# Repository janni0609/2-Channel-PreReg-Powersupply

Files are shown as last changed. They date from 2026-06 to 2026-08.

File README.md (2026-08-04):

# 2-Channel Pre-Regulated Bench Power Supply

A two-channel laboratory bench power supply, **0–36 V / 0–2 A per channel**, fully
isolated between channels. Each channel pairs a **tracking switch-mode
pre-regulator** with a **linear post-regulator**, so it has the low output noise of
a linear supply without the heat of dropping 36 V across a pass transistor.

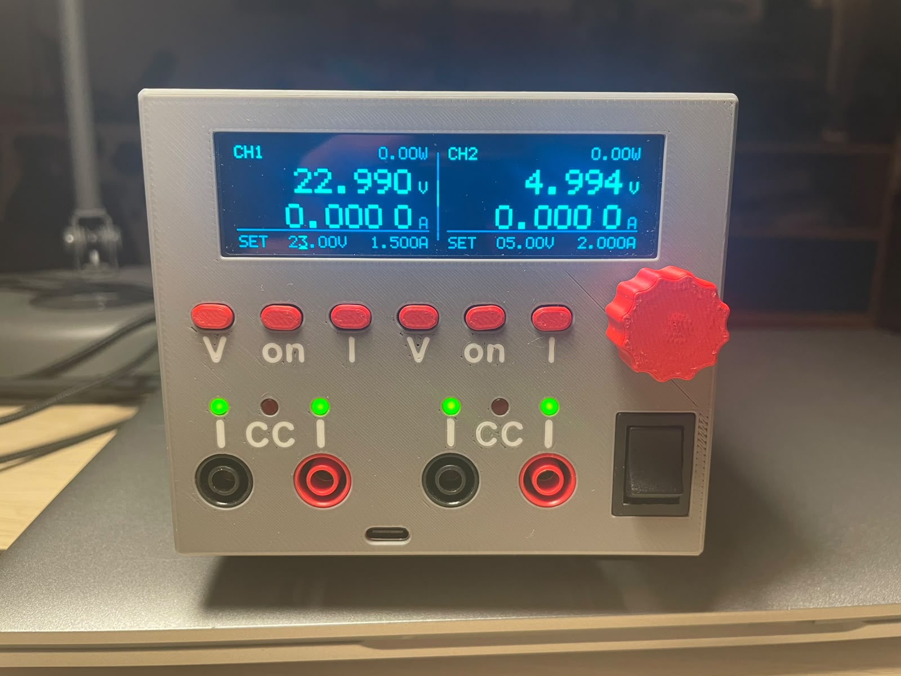
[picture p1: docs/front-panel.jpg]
Front panel of the assembled supply, both channels running


Everything here is open: KiCad 10 schematics and layout for both boards, the
firmware for all three microcontrollers, and the design calculations (loop
stability, DC/DC dimensioning, ADC/DAC error budget) that back the component
values.

**Status: built and working.** Both PCBs are assembled and running. One known
footprint error, see [Known issues](#known-issues).

**Schematics in your browser (KiCanvas):**
[Main board](https://kicanvas.org/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)
· [Front panel](https://kicanvas.org/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)

---

## Specifications

| Parameter | Value |
| --- | --- |
| Channels | 2, independent, galvanically isolated from each other and from the control logic |
| Output voltage | 0 … 36 V per channel |
| Output current | 0 … 2 A per channel (setpoint = current limit, CV/CC) |
| Setpoint resolution | 12-bit DAC ≈ 8.6 mV / 0.49 mA; front panel edits in 10 mV / 1 mA steps |
| Measurement resolution | 16-bit ADC, ~1.9 mV / ~0.1 mA; displayed as 3 decimals (V) and 4 decimals (A) |
| Accuracy | ±3–4 % uncalibrated (DAC band gap dominates). **Measured after calibration, worst of both channels: setpoint ±17 mV / ±1.3 mA, readback ±2.8 mV / ±3.7 mA** — see [Measured accuracy](#measured-accuracy) |
| Protection | Per-channel over-temperature (settable, default 60 °C), system OTP on the heatsink, comms-loss shutdown, input fuses + TVS |
| Regulation | Analog CV and CC loops per channel; MCU sets the references, does not close the loop. CC is indicated by a panel LED driven straight from the loop |
| Display | 256×64 SSD1322 OLED |
| Remote control | SCPI over Ethernet (raw TCP, port 5025) and USB CDC (front-panel USB-C) |
| Cooling | Temperature-controlled 4-wire PWM fan |
| Input | 2 × 40 V DC (channels) + 12 V DC (logic) — see [Power input](#power-input) |

---

## How it works

### Power path (one channel)

```text
40 V in ──▶ LT8612 tracking buck ──▶ Vpre = Vout + 2.2 V ──▶ TIP125 linear pass ──▶ OUT
                    ▲                                              ▲
                    └────────── follows the output ────────────────┘
```

The buck converter does not produce a fixed rail — it **tracks the output**,
holding just 2.2 V of headroom across the linear stage. At full load that is
~200 mV across the 0.1 Ω shunt plus ~2 V across the TIP125 Darlington, i.e. a few
watts of dissipation instead of the ~70 W a plain 40 V linear supply would burn at
0 V out into 2 A.

The linear stage is a classic op-amp regulator built around a **TIP125** PNP
Darlington driven by a **TLV4387** quad op-amp:

- **Voltage loop** — a 4-resistor difference amplifier across OUT+/OUT− scales the
  output by 1/15 (0.06935) and compares it against `Vset` from the DAC.
- **Current loop** — a 0.1 Ω shunt (PCS2512, 1 %, 0.4 W at 2 A) is amplified ×12.25
  and compared against `Iset`. Whichever loop demands less current wins, giving
  automatic CV → CC crossover. The crossover point itself is picked off as a
  `CC/CV` signal that lights the front-panel **CC** lamp directly — no firmware in
  the path, so the indicator is as fast as the loop it reports on.

Both loops are compensated deliberately, not guessed — see
[`Calc/Stability/`](Calc/Stability/) for the plant models, the chosen compensator
values, and the loop-gain / step-response plots.

Per-channel auxiliary rails come off the 40 V input: **LMR51606** buck → 4.5 V,
**AP7384-33Y** → 3.3 V for the MCU and converters, and an **LM2776** charge pump +
**XC6901** negative LDO → −1.2 V so the op-amps can swing cleanly down to 0 V.

### Control architecture

```text
        ┌──────────────── Front panel ────────────────┐
        │  SSD1322 OLED · encoder · 6 buttons · LEDs  │
        └──────────────────────┬──────────────────────┘
                               │ SPI / I²C
                    ┌──────────┴──────────┐        ┌──────────────┐
   Ethernet ────────┤   RP2350 "Brain"    ├────────┤ W5500 · USB  │ SCPI
                    └─────┬─────────┬─────┘        └──────────────┘
                UART0 ◄───┘         └───► UART1     (1 Mbps, ISO6721 isolated)
                  │                         │
        ┌─────────┴────────┐      ┌─────────┴────────┐
        │ ATtiny1614  CH1  │      │ ATtiny1614  CH2  │
        │ ADS1118 · MCP48F │      │ ADS1118 · MCP48F │
        └──────────────────┘      └──────────────────┘
```

Each channel has its own **ATtiny1614** living in that channel's isolated ground
domain. It drives the **MCP48FVB22** dual DAC (the V and I references for the
analog loops), reads the **ADS1118** 16-bit ADC (output voltage and shunt current),
monitors an NTC, sequences the two enable lines, and stores its calibration in
EEPROM. Over-temperature shutdown happens in the channel MCU itself, so a hung
UART link can never leave an output enabled.

The **RP2350** brain owns the user interface and all remote control. It never
touches the analog loops directly; it only sends setpoints and reads telemetry
over the two isolated 1 Mbps UART links.

---

## Boards

### `hardware_main/` — main board (`DualPreRegPowerSupply.kicad_pro`)

Both power channels, both channel MCUs, the brain, and the digital supply on one
PCB. Hierarchical sheets:

| Sheet | Contents |
| --- | --- |
| `Ch1Power` (×2 instances) | One complete channel — the sheet below is instantiated twice |
| ├ `Input` | 40 V input, fuse, TVS, common-mode choke |
| ├ `Power` | Channel aux rails: 4.5 V, 3.3 V, −1.2 V |
| ├ `DCDCTracking` | LT8612 tracking pre-regulator |
| ├ `Linear_PostReg` | TIP125 pass element, V and I loops, shunt, sense amps |
| ├ `DAC_ADC` | MCP48FVB22 DAC, ADS1118 ADC, filtering |
| └ `MCU` | ATtiny1614, NTC, ISO6721 isolated UART, UPDI header |
| `Control` | RP2350-Tiny, W5500 Ethernet, front-panel connectors, fan |
| └ `Digi_Power` | 12 V input → AP63200WU → 3.3 V logic rail |

Fabrication outputs (Gerbers, BOM, CPL) are in
[`hardware_main/production/`](hardware_main/production/); an interactive BOM is at
[`hardware_main/bom/ibom.html`](hardware_main/bom/ibom.html).

### `hardware_front/` — front panel (`Front Panel.kicad_pro`)

The user interface board: SSD1322 OLED header, rotary encoder with push button,
6 push buttons, 6 status LEDs (per channel: two green output-ON indicators, one
over each banana-jack pair, plus the red CC lamp), buzzer, and an **MCP23008** I²C
expander that collects the buttons and drives the buzzer. The green indicators run
off the corresponding channel's isolated 3.3 V rail, so each half of the panel
stays in its own ground domain. Fabrication outputs in
[`hardware_front/production/`](hardware_front/production/).

---

## Firmware

Both projects build with **PlatformIO**.

### `firmware/brain/main/` — RP2350 brain

Waveshare RP2350-Tiny (built against `waveshare_rp2350_zero`). Handles the OLED
UI, encoder and buttons, fan control, the UART links to both channels, and the
SCPI server on Ethernet + USB.

```sh
cd firmware/brain/main
pio run                 # build
pio run -t upload       # flash (UPF2 / USB bootloader)
```

RP2350 pin map (also documented at the top of `platformio.ini`):

| Function | Pins |
| --- | --- |
| OLED SSD1322 (SPI1) | RES 9, SCK 10, MOSI 11, DC 12, CS 13 |
| Rotary encoder (PIO quadrature) | A 14, B 15 |
| W5500 Ethernet (SPI0) | CS 17, SCK 18, MOSI 19, MISO 20, RST 21, INT 22 |
| MCP23008 expander (I²C1) | SDA 6, SCL 7, INT 8 |
| Channel UARTs @ 1 Mbps | CH1: TX 0 / RX 1 · CH2: TX 4 / RX 5 |
| Heatsink NTC / fan PWM | ADC3 (GPIO29) / GPIO26 (25 kHz) |

[`firmware/brain/UI-test/`](firmware/brain/UI-test/) is the earlier UI-only
prototype the production firmware grew out of; it is kept for display work without
the power hardware attached.

### `firmware/channel/` — ATtiny1614 channel

megaTinyCore, 16 MHz internal oscillator, flashed over UPDI. Layered cooperative
super-loop with an explicit state machine
(`INIT → SELFTEST → IDLE ↔ RUN → FAULT`). See
[`firmware/channel/README.md`](firmware/channel/README.md) for the module tree,
the state machine, and the calibration procedure.

```sh
cd firmware/channel
pio run -t fuses        # once: set OSCCFG to 16 MHz (required!)
pio run -t upload       # flash over UPDI
```

> The `-t fuses` step is not optional on a fresh part. The default fuse selects the
> 20 MHz oscillator base; with a 16 MHz build every timing (UART baud, delays,
> telemetry period) comes out 25 % off.

### Brain ↔ channel protocol

A small binary framing: `[SOF 0xA5][LEN][CMD][payload][CRC8]`, defined in
`firmware/channel/include/protocol.h` (mirrored into the brain project). The
channel pushes a telemetry frame every 100 ms (V, I, P, temperature, state,
flags) and ACK/NACKs every command. If the brain goes quiet for 1 s while an
output is on, the channel turns that output off by itself.

---

## Remote control (SCPI)

The instrument speaks an **SCPI-1999 / IEEE-488.2 subset** on two transports at
once — raw TCP port 5025 over Ethernet, and USB CDC — so it works with PyVISA,
NI-MAX, `lxi`, or a plain terminal.

```text
*IDN?                 → PreReg,PSU-2CH-36V2A,SN00001,0.2.0
APPL CH1,12.0,1.0
OUTP ON,(@1)
MEAS:VOLT? (@1)       → 12.001
MEAS:CURR? (@1)       → 0.2531
```

Channel lists (`(@1)`, `(@1,2)`) and stateful `INST:NSEL` selection are both
supported, along with the STATus register model, an error queue, and the
CALibration subsystem. The full command reference — including UART mappings and
known deviations — is in [`firmware/SCPI/commands.md`](firmware/SCPI/commands.md).

Network settings (DHCP or static IP, netmask, gateway, hostname) are configured
from the front panel under *Settings → Network*, and only take effect on **Apply**,
so a half-typed IP never goes live.

---

## Front panel

The main screen shows both channels side by side: measured voltage and current in
large digits, output power in the corner, and the active setpoints on the bottom
row. Six buttons (`V · on · I` per channel) select what the encoder edits and
toggle each output; the encoder push button moves the digit cursor — underlined on
screen — so any digit can be dialled directly instead of scrolling through the
whole range.

Below the buttons, each channel has two green output-ON LEDs flanking a red **CC**
lamp that lights whenever that channel leaves constant-voltage regulation, then the
output banana jacks. The USB-C port for SCPI-over-USB and firmware updates sits in
the middle of the panel; the mains switch is on the right. The enclosure is 3D
printed.

The Settings menu (encoder-driven, see
[`firmware/brain/UI-test/Settings.md`](firmware/brain/UI-test/Settings.md))
covers per-channel diagnostics (temperature, DAC/ADC/comms health, operating
hours, stored calibration values, the manual 2-point calibration wizard), the
temperature and fan curve (start temp, max temp, minimum speed, system OTP),
the network configuration, and system items (firmware version, beeper, brain
runtime, remember-setpoints-on-restart).

---

## Calibration

Every signal path — `VSET`, `ISET`, `VMEAS`, `IMEAS`, per channel — is a straight
line `y = gain·x + offset` fitted from two points and stored in the channel's
EEPROM. This is **required**, not optional: the MCP48FVB22 uses its internal
1.22 V band gap (Vref is not routed on the PCB), and that band gap is specified to
±3.3 %. Calibration removes it, along with the 1 % resistor and shunt tolerances,
leaving roughly ±0.05 % on voltage and ±0.1–0.2 % on current. Until a channel has
been calibrated it reports `FLAG_CAL_INVALID`.

Run it from the front panel (*Settings → Channel n → Manual Cal V/I*, with a
DMM on the output) or remotely via `CAL:POIN` / `CAL:COMM`. Full error budget and
where each term comes from:
[`Calc/DAC_ADC/DAC_ADC_Accuracy_Analysis.md`](Calc/DAC_ADC/DAC_ADC_Accuracy_Analysis.md).

---

## Measured accuracy

Both channels were measured against a **Siglent SDM3065X** 6½-digit DMM on
2026-08-03/04, using [`Calc/evaluation/psu_accuracy.py`](Calc/evaluation/) — a
ramp of the full range in fine steps, comparing three numbers at every step:

| | source | exercises |
| --- | --- | --- |
| setpoint | what was written with `VOLT` / `CURR` | DAC → `VSET`/`ISET` chain |
| readback | `MEAS:VOLT?` / `MEAS:CURR?` | sense amp → ADC → `VMEAS`/`IMEAS` chain |
| truth | SDM3065X | — |

Voltage: 0 → 36 V in 500 mV steps, open circuit. Current: 0 → 2 A in 25 mA steps
into the DMM's own current input as the load, 2 V compliance. Figures are for the
instrument **as it stands today**, i.e. calibrated, and exclude the two endpoints
the channel physically cannot reach: the 0 V / 0 A setpoint (output floor, not an
accuracy error) and the clipped top of the current range (see
[Known issues](#known-issues)). `psu_accuracy.py` applies both exclusions itself,
so these numbers come straight out of its report; `--keep-endpoints` reports every
point instead.

### Results

| | CH1 setpoint | CH1 readback | CH2 setpoint | CH2 readback |
| --- | --- | --- | --- | --- |
| **Voltage** rms | 8.8 mV | **0.74 mV** | 5.1 mV | 1.4 mV |
| worst | 16.5 mV | 2.1 mV | 11.6 mV | 2.8 mV |
| gain error | −0.0005 % | +0.0025 % | −0.0024 % | −0.0003 % |
| **Current** rms | **0.30 mA** | 0.12 mA | **0.52 mA** | 0.16 mA |
| worst | 0.79 mA | 0.39 mA | 1.36 mA | 0.51 mA |
| gain error | +0.012 % | +0.013 % | +0.035 % | +0.019 % |

Both current columns were re-measured on 2026-08-04, after the measure-path
calibration bug was found and fixed and both channels' `IMEAS` re-calibrated.
The readback paths went from 0.78 mA rms / +0.135 % gain / −1.38 mA offset (CH1)
and 2.0 mA rms / +0.176 % gain (CH2) to the numbers above — an order of
magnitude, and the −1.4 mA offset that had been blamed on the shunt turned out to
be an artefact of the bad fit.

In short, worst of both channels: **voltage setpoint ±17 mV (≈0.05 % FS), voltage
readback ±2.8 mV, current setpoint ±1.4 mA (≈0.07 % FS), current readback
±0.51 mA**. Every voltage gain error is inside ±0.003 % and every current gain
error is now inside ±0.04 %, so the calibration is doing its job on every path.
The current readback is at ~5 ADC LSB worst case.

<picture>
  <source media="(prefers-color-scheme: dark)" srcset="Calc/evaluation/results/ramp_v_ch1_20260804_231349_ch1_v_baseline_dark.png">
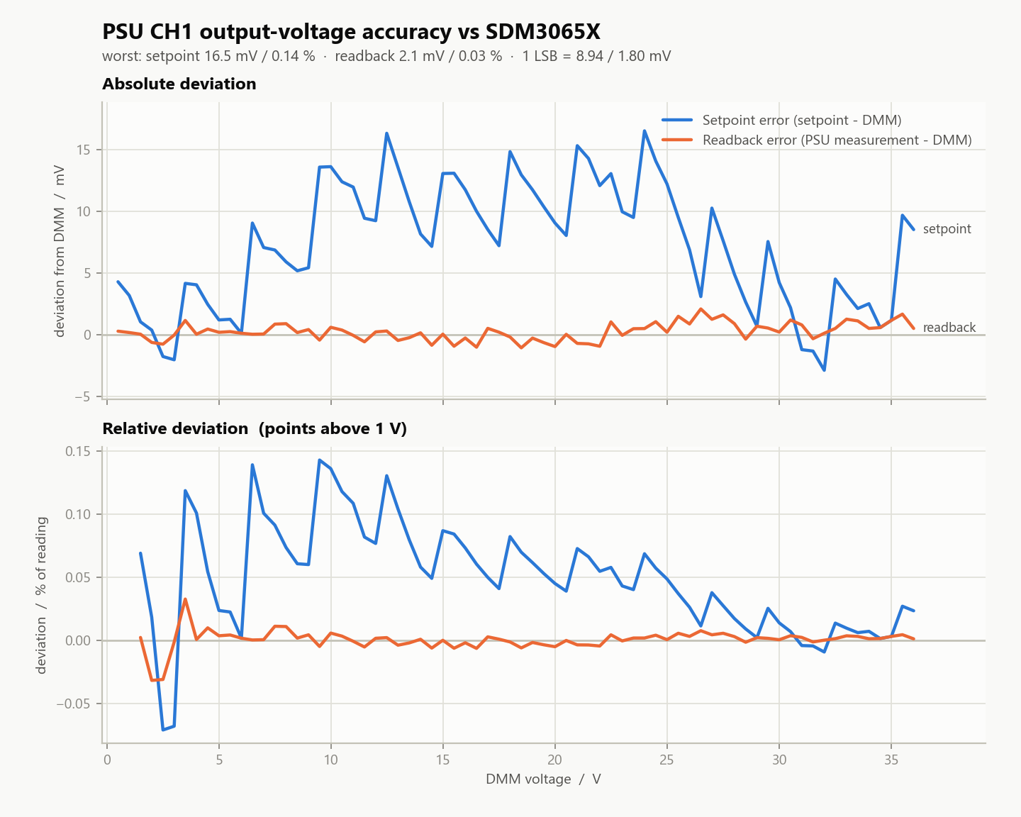
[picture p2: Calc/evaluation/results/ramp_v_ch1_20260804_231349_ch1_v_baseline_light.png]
CH1 output-voltage accuracy against the SDM3065X: absolute and relative deviation
  
</picture>

The voltage setpoint trace is the interesting one. Its error is **not**
calibration error — it is the 12-bit DAC. The sawtooth is the ±½ LSB rounding of
a requested millivolt onto the ~8.9 mV code grid, and the slow envelope on top is
the DAC's own INL (specified ±2 LSB). A 2-point calibration pins the two
endpoints and cannot bend to follow a bow between them, which is why
re-calibrating an already-calibrated channel here changes nothing. The readback
trace sits flat at the ADC's ~1.8 mV quantum. **This is the hardware floor, not a
tuning problem** — improving it needs an external DAC reference (the `Vref` pin is
not routed) or more DAC bits.

<picture>
  <source media="(prefers-color-scheme: dark)" srcset="Calc/evaluation/results/ramp_i_ch1_20260804_224335_ch1_imeas_fix_dark.png">
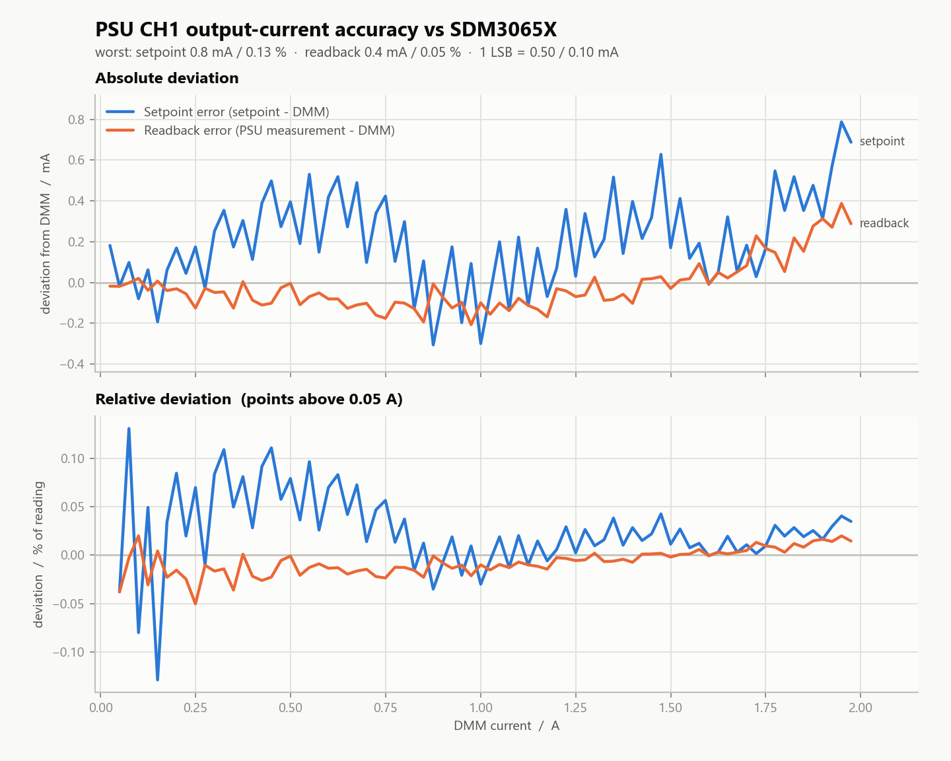
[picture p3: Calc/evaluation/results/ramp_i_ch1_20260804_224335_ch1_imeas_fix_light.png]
CH1 output-current accuracy against the SDM3065X after calibration
  
</picture>

Current is the opposite case, and shows what calibration *can* do. Both of CH1's
current paths were a clean tilt beforehand — an error proportional to reading,
which is exactly the shape a 2-point fit removes. The setpoint went from +0.176 %
gain (−1.2 mA at 100 mA rising to +1.8 mA at 2 A) to +0.012 %, rms 0.89 →
0.30 mA; the readback went from +0.135 % gain with a −1.38 mA offset to
+0.013 %, rms 0.78 → 0.12 mA. Both traces are now flat inside ±0.8 mA across the
range, with the readback at ~4 ADC LSB. CH2 behaves the same way.

**Rule of thumb from this:** plot the error against reading before calibrating. A
*tilt*, or a constant offset, is gain/offset error and a 2-point fit removes it
exactly. A *bow* between the cal points is INL and it will not — which is why the
voltage setpoint above does not improve however often it is re-run. The report's
`worst non-linearity` row measures that bow; compare it against the quantisation
floor printed beneath it.

All raw data, per-run reports and both channels' plots are in
[`Calc/evaluation/results/`](Calc/evaluation/results/); the harness, wiring and
options are documented in [`Calc/evaluation/README.md`](Calc/evaluation/README.md).

---

## Power input

The supply is fed from three off-the-shelf Mean Well modules:

| Input | Supply | Feeds |
| --- | --- | --- |
| J101 | Mean Well **LRS-75-36**, trimmed to **40 V** | Channel 1 |
| J601 | Mean Well **LRS-75-36**, trimmed to **40 V** | Channel 2 |
| J901 | Mean Well **RS-15-12** (12 V) | Brain, OLED, Ethernet, fan |

Each channel input has its own 3.5 A fuse, TVS clamp, and common-mode choke.
Because the two channel supplies are separate isolated modules and the UART links
are isolated with ISO6721 digital isolators, the two outputs are genuinely
floating and independent — they can be wired in series or referenced separately.

Outputs terminate in front-panel banana jacks (J201/J202 and J402/J403).

---

## Repository layout

```text
hardware_main/     KiCad 10 project — main board (power, MCUs, brain)
hardware_front/    KiCad 10 project — front panel (OLED, encoder, buttons)
firmware/
  brain/main/      RP2350 production firmware (UI + comms + SCPI)
  brain/UI-test/   Earlier UI-only prototype
  channel/         ATtiny1614 channel firmware
  SCPI/            SCPI command reference
  requirements/    Original firmware requirements notes
  Datasheets/      Datasheets for the main ICs
Calc/
  Stability/       V and I loop compensation — notebooks + typeset report
  DCDC Calc/       LMR51606 40 V → 4.5 V aux buck design
  DAC_ADC/         Setpoint/measurement error budget
  evaluation/      Bench accuracy measurement vs a reference DMM (+ raw results)
```

---

## Design notes and calculations

- [`Calc/Stability/stepbystep/`](Calc/Stability/stepbystep/) — Jupyter notebooks
  deriving the voltage and current loop transfer functions (including the TIP125's
  β(s) roll-off and the op-amp GBW corner), the chosen compensator values, load
  sweeps, and step responses. The typeset summary is
  `Calc/Stability/stepbystep/report/loop_analysis.pdf`.
- [`Calc/DCDC Calc/LMR51606X_40V_4V5_200mA_design.md`](Calc/DCDC%20Calc/LMR51606X_40V_4V5_200mA_design.md)
  — full worked design of the 40 V → 4.5 V auxiliary buck.
- [`Calc/DAC_ADC/DAC_ADC_Accuracy_Analysis.md`](Calc/DAC_ADC/DAC_ADC_Accuracy_Analysis.md)
  — where every microvolt of error comes from, and what calibration does and does
  not fix.

---

## Known issues

- **AP7384-33Y footprint (channel 3.3 V LDO)** — the footprint on the main board is
  wrong; the part needs rework/adaptation to fit. Fix before ordering new boards.
- The ADS1118 PGA is **pinned to ±4.096 V** rather than autoscaling. Each PGA range
  has its own gain/offset error and input impedance, so a single 2-point cal line
  cannot describe all of them — autoscaling made readings drift away from the
  calibration points. Re-enabling it requires per-range calibration
  (`ADC_PGA_*_INDEX` in `firmware/channel/include/config.h`).
- **Neither channel reaches its rated 2.000 A.** The ISET DAC clips at ~1.99 A on
  CH1 and ~1.95 A on CH2 (both setpoints above the ceiling return the identical
  current, and the readback agrees). Full scale is 2.44 V ÷ 1.225 V/A = 1.99 A,
  but `DEFAULT_I_DIV` in `calibration.cpp` assumes 1.2 → 2.033 A and
  `SETPOINT_I_MAX_MA` is 2000; the channel spread on top is band-gap and shunt
  tolerance. The top ~1–2 % of the current range is not reachable.
- `CALibration:DATA?` returns NaN over SCPI: gain/offset cannot currently be read
  back across the channel link. `CAL:POINt`/`CAL:COMMit` are also fire-and-forget
  — the channel's NACK lands in `lastNackCmd` and the SCPI handler never looks at
  it — so a rejected commit is invisible to the host. Between them these kept a
  (now fixed) measure-path calibration bug hidden for far longer than it should
  have been. Until they are addressed, re-drive the cal points and check the
  readback residual (as `psu_accuracy.py` now does) rather than trusting
  `CAL:VALid?`.
- **A setpoint written immediately after `CAL:COMMit` is occasionally dropped.**
  Seen 3/3 times as the first `CURR` after committing `IMEAS` in a full
  calibration sequence, and 0/17 in isolated retries — so it is real but not yet
  root-caused. Ruled out: the channel is not stalled by the EEPROM write (the
  link never drops, `OUTP?` held over 3592 samples across a commit), and it is
  not a frame-size overflow. Leave a settle after a commit, and verify setpoints
  actually landed before measuring against them.
- The hostname set in *Settings → Network* is stored and displayed, but the stock
  Ethernet DHCP client does not advertise it to the DHCP server.
- The CV/CC mode is shown on the panel by a hardware-driven LED, but the `CC/CV`
  signal is not routed to a channel MCU pin, so the regulation mode cannot be
  queried over SCPI (`STAT:OPER` has no constant-current bit).

---

## Tools

KiCad 10 · PlatformIO (`raspberrypi` + `atmelmegaavr` platforms) · megaTinyCore ·
Arduino-Pico core · Python/Jupyter for the analysis notebooks.

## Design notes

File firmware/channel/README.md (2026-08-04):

# Channel firmware (ATtiny1614)

Firmware for one power-supply **channel** MCU. Each channel drives its own
ADC + DAC and talks to the **Brain** (RP2350) over UART. Built with
**megaTinyCore** (Arduino) under PlatformIO.

## Build / flash

```sh
pio run                 # build
pio run -t upload       # flash via UPDI (SerialUPDI by default)
pio device monitor      # 1000000 baud (1 Mbps), the Brain link
```

Adjust `upload_protocol` in `platformio.ini` for your UPDI programmer.

**Flashing does not wipe the calibration.** `-t upload` chip-erases, but both
chips have `SYSCFG0 = 0xC5`, i.e. the EESAVE fuse is set, so EEPROM survives
(verified by reading it back byte-for-byte either side of an upload). If that
fuse is ever cleared, back the EEPROM up first and restore it afterwards:

```sh
avrdude -c serialupdi -p attiny1614 -P COM<n> -b 115200 -U eeprom:r:backup.bin:r
```

That same read is currently the only way to recover the stored gain/offset
values, since `CAL:DATA?` returns NaN over SCPI.

## Architecture

Layered, cooperative super-loop (no RTOS). One shared `g_state` is the single
source of truth; modules update it, `comms` serializes it into telemetry.

```
main.cpp            super-loop scheduler + g_state
fsm.cpp             INIT -> SELFTEST -> IDLE <-> RUN -> FAULT
include/
  config.h          pin map, limits, tunables
  protocol.h        shared binary UART protocol (COPY into the Brain project)
src/hal/
  spi_bus.*         shared SPI, per-device mode switch + CS framing
  board.*           enable lines + NTC analog input
  storage.*         calibration EEPROM (magic + version + CRC16)
src/drivers/
  ads1118.*         16-bit ADC: single-shot, config readback self-test
  mcp48fvb22.*      dual 12-bit DAC: band-gap ref, gain 1x
src/app/
  measure.*         non-blocking V/I acquisition, PGA autoscale, power
  setpoint.*        engineering setpoint -> DAC code (via calibration)
  calibration.*     2-point linear cal for the 4 paths
  thermal.*         NTC -> degC, over-temp protection (independent of comms)
  output.*          enable sequencing (DCDC first, then linear)
  selftest.*        power-on ADC/DAC/temperature checks
  comms.*           frame parser, dispatch, telemetry/ACK/EVENT
```

### State machine

`SELFTEST` runs on boot; on pass -> `IDLE` (output off). `SET_OUTPUT 1` from
`IDLE` -> `RUN`. Over-temperature (>= 60 °C) from any state -> `FAULT`, which
forces both enable lines low. `FAULT` clears only via `RESET_FAULT` once the
temperature has dropped below 55 °C (hysteresis), then re-runs `SELFTEST`.

Over-temp protection runs in the thermal task + FSM, so a hung UART can never
keep the output enabled.

## UART protocol

Frame: `[SOF 0xA5][LEN][CMD][payload...][CRC8]`, little-endian, CRC-8 poly
0x07. See `include/protocol.h` for command IDs and payloads. The Channel pushes
`TELEMETRY` every 100 ms and ACK/NACKs every command; the Brain can also poll
with `GET_STATUS`.

Telemetry payload (16 B): `v_mV(i32) i_dmA(i32) p_mW(i32) temp_cC(i16)
state(u8) flags(u8)`.

## Calibration

Every signal path is `y = gain*x + offset`, calibrated from two points and
stored in EEPROM. Procedure, per target (`CAL_VSET/ISET/VMEAS/IMEAS`):

1. Drive a low point (set a setpoint, or just read at low signal), measure the
   true value externally, send `CAL_POINT{target, index=0, actual}`.
2. Repeat for a high point with `index=1`.
3. `CAL_COMMIT{target}` solves and persists the line.

`CAL_RESET{target}` restores compile-time defaults.

## Pin map (corrected from requirements)

| Signal | Pin  | Notes |
|---|---|---|
| SPI MOSI | PA1  | shared bus (ADC + DAC) |
| SPI MISO | PA2  | shared bus |
| SPI SCK | PA3  | shared bus |
| ADC_CS | PA4  | **was PA3 in requirements (collided with SCK)**  |
| DAC_CS | PA7  | |
| DAC_LAT | PA6  | held low (transparent latch) |
| Enable_DCDC  | PB1  | pre-regulator |
| Enable_lin | PA5  | linear post-regulator |
| NTC | PB0  | 10k NTC, Rtop=10k to VDD |
| UART TX/RX | PB2/PB3 | USART0 -> the `Serial` object |

## Assumptions to confirm

These were chosen to make the firmware complete and buildable; please verify
against the hardware:

1. **ADC_CS = PA4** (requirements listed PA3, which is SCK).
2. **Enable sequence**: pre-regulator (DCDC) is enabled before the linear
   stage, and disabled after it. Swap in `output.cpp` if the hardware wants the
   opposite order.
3. **Setpoint units**: `SET_VOLTAGE`/`SET_CURRENT` carry mV/mA. The default
   (uncalibrated) map treats them as desired DAC output mV (0..2440). The real
   mapping to the supply's output range is established by 2-point calibration;
   `FLAG_CAL_INVALID` is reported until then.
4. **DAC reference**: internal band gap, gain 1x -> 0..2.44 V full scale (the
   "0..2.5 V" spec). The band gap is ±3.3 %, so calibration is required.
5. **ADS1118 PGA** starts at ±4.096 V and autoscales up for small signals; the
   front end is assumed to keep inputs within ±4.096 V at full output.

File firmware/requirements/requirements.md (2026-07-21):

the firmware is for a lab bench powersupply projekt. 
the architecture of the powersupply is as follows

RP2350 (Waveshare RP2350-Tiny) is the main "brain".

the Powersuppy has two channes. each channes has its own MCU (Attiny 1614) that communicates with the ADC and DAC + periphials.

each attiny (i will call it channel) is connected to the RP2350 (i will call it brain) via UART.

**requirements for the Brain:**

it has to communicate with the channes.
    the brain should be able to send the channel a set volatage, set current, output state(on/off)

the Display has to be used (see ????? for a referance)

the brain is connected to an MCP23008 I/O expander via i2c (I2C1, 400 kHz fast mode).
    the MCP23008 has a rotary encoder connected and 6 buttons + 1 button on the encoder
    it also has a buzzer connected

**requirements for the channes:**

Attiny1614 at 3,3V
programmed at with platformIO.

the channel has to communicate with the brain. UART: (Tx -- PB2; Rx -- PB3)
Data to send to the Brain:
Output Volatge
Output Current
Output Power
Temperatur
Output State  (on/off)
Error messages

Data to recieved from Brain:
Set Volt
Set Current
Output State (on/off)
Data for calibration

the channel has to read the ADC (ADS1118IDGS) (SPI: MOSI -- PA1; MISO -- PA2; SCK -- PA3; ADC_CS -- PA4;)
Vmeas = AIN1 and AIN0
Imeas = AIN2 and AIN3
Do autoscaling of the input PGA

set the DAC (MCP48FVB22) (SPI: MOSI -- PA1; MISO -- PA2; SCK -- PA3; DAC_CS -- PA7; DAC_LAT -- PA6)
Vset = VOUT0
Iset = VOUT1
use internal reference
output 0 to 2,5V

The ADC and DAC has to be calibrated by a 2 point calibration.
for the calibration: a voltage/current will be set on the cannel and the actual measured volatge / current will be send by the brain. channel has to calculate cal values and store them in the eeprom

It has to be able to turn the output on and off with (Enable_DCDC -- PB1; Enable_lin -- PA5)

It has to read a NTC 10KOHM 3380K (PB0), NTC is set up with a R devider Rtop = 10k; Rbot = NTC

a self test has to be performed on startup:
test propper communication with chips and check if temp is in range (-10 to 60°C)

Output has to be turned off if temp reaches >60°C

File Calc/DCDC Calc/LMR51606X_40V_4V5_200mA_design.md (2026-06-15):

# LMR51606X Buck Converter Design — 40 V → 4.5 V @ 200 mA

Synchronous step-down (buck) converter design based on the **Texas Instruments LMR51606**
(datasheet *SLUSEY1B*, Rev. December 2023, located in this folder as `lmr51606.pdf`).

---

## 1. Design inputs & top-level decisions

| Parameter | Value | Source |
|---|---|---|
| Input voltage, V<sub>IN</sub> | **40 V** (treated as worst-case / max for ripple) | spec |
| Output voltage, V<sub>OUT</sub> | **4.5 V** | spec |
| Output current, I<sub>OUT</sub> | **200 mA** | spec |
| Switching frequency, f<sub>SW</sub> | **400 kHz** | fixed by "X" suffix |
| Reference voltage, V<sub>REF</sub> | **0.8 V** (±1.5 %) | datasheet §6.5 |
| Inductor ripple ratio, K<sub>IND</sub> | **≈ 0.5** | design choice (smaller L / more ripple) |
| EN / input UVLO | **EN tied directly to V<sub>IN</sub>** | design choice |
| Light-load mode | **PFM / auto-mode** | design choice |
| **Orderable part** | **LMR51606XDBVR** | 0.6 A, 400 kHz, PFM, adjustable, SOT-23-6 |

**Device suitability check:**
- V<sub>IN</sub> = 40 V is inside the 4 V–65 V operating range (abs. max 70 V). ✔
- 0.6 A device rating vs. 0.2 A load → **3× current headroom**. ✔
- V<sub>OUT</sub> = 4.5 V is inside the 0.8 V–28 V adjustable range. ✔

> **Note on input range:** the design is worst-cased at V<sub>IN</sub> = 40 V (the point of highest
> ripple current). It stays valid for any lower or varying input down to ≈ 4.9 V (see §2). If 40 V is
> actually the *minimum* of a higher range, the inductor and ripple numbers must be recomputed at the
> true maximum input.

---

## 2. Operating point & frequency-foldback check

Ideal buck duty cycle:

```
D = VOUT / VIN = 4.5 / 40 = 0.1125  (11.25 %)

tON  = D / fSW        = 0.1125 / 400 kHz   = 281 ns
tOFF = (1 - D) / fSW  = 0.8875 / 400 kHz   = 2219 ns
```

Compare against the device limits (datasheet §6.5 / §7.3.4):

| Limit | Value | Our value | OK? |
|---|---|---|---|
| Min ON time, t<sub>ON_MIN</sub> | 80 ns | 281 ns | ✔ (3.5×) |
| Max ON time, t<sub>ON(max)</sub> | 5 µs | 281 ns | ✔ |
| Min OFF time, t<sub>OFF_MIN</sub> | 200 ns | 2219 ns | ✔ (11×) |

Maximum / minimum input voltage **without** frequency foldback (Eq. 4 / Eq. 5):

```
VIN_MAX = VOUT / (fSW × tON_MIN)   = 4.5 / (400 kHz × 80 ns) = 140.6 V
VIN_MIN = VOUT / (1 - fSW × tOFF_MIN) = 4.5 / (1 - 0.08)     = 4.89 V
```

→ At V<sub>IN</sub> = 40 V the converter runs at a **clean fixed 400 kHz with no frequency foldback**.

---

## 3. Output-voltage feedback divider (R<sub>FBT</sub> / R<sub>FBB</sub>)

Datasheet Eq. 1 / Eq. 7:  `RFBT = (VOUT − VREF)/VREF × RFBB`

Required ratio: `RFBT/RFBB = (4.5 − 0.8)/0.8 = 4.625`

Chosen standard E96 (1 %) pair:

| Resistor | Value | Notes |
|---|---|---|
| **R<sub>FBT</sub>** (V<sub>OUT</sub> → FB) | **75.0 kΩ, 1 %** | within recommended 10 k–100 kΩ range |
| **R<sub>FBB</sub>** (FB → GND) | **16.2 kΩ, 1 %** | sets divider current |

Resulting output voltage:

```
VOUT = VREF × (1 + RFBT/RFBB) = 0.8 × (1 + 75.0k/16.2k) = 4.504 V   (+0.08 % vs target)
Idivider = VREF / RFBB = 0.8 / 16.2k = 49 µA
```

> Nominal set-point error is +0.08 %. The dominant error is component tolerance: ±1.5 % (V<sub>REF</sub>)
> plus ≈ ±1.4 % (two 1 % resistors, RSS) → use 1 % (or 0.5 %) resistors with a low temperature
> coefficient as recommended by TI. Place both resistors next to the FB pin (§9).

---

## 4. Inductor (L)

Minimum inductance, datasheet Eq. 9, with K<sub>IND</sub> = 0.5:

```
LMIN = (VIN_MAX − VOUT)/(IOUT × KIND) × VOUT/(VIN_MAX × fSW)
     = (40 − 4.5)/(0.2 × 0.5) × 4.5/(40 × 400 kHz)
     = 99.8 µH
```

→ **Choose a standard 100 µH inductor.**

Resulting ripple and currents (Eq. 8) with L = 100 µH:

```
ΔiL   = VOUT × (VIN_MAX − VOUT) / (VIN_MAX × L × fSW) = 99.8 mA   (KIND_actual = 0.50)
IL,peak   = IOUT + ΔiL/2 = 200 + 50 = 250 mA
IL,valley = IOUT − ΔiL/2 = 200 − 50 = 150 mA   (> 0 → continuous conduction at full load)
IL,rms    ≈ √(IOUT² + ΔiL²/12) = 202 mA
```

**Inductor selection requirements:**

| Parameter | Requirement | Reasoning |
|---|---|---|
| Inductance | **100 µH** (±20 %) | from Eq. 9, K<sub>IND</sub> = 0.5 |
| Saturation current, I<sub>sat</sub> | **≥ 1.5 A** | above the device max HS peak current limit (1.4 A) so the core does not saturate during an overload/short before cycle-by-cycle limiting acts |
| RMS current rating | **≥ 0.3 A** | operating I<sub>rms</sub> ≈ 0.2 A + margin |
| DCR | **≤ ~0.3 Ω** (lower = better) | efficiency; 0.3 Ω → ~12 mW loss |
| Type | Shielded ferrite | low EMI |

> If board size is critical, an inductor with I<sub>sat</sub> ≥ ~1.0 A still operates safely (operating peak
> is only 250 mA, and the IC's cycle-by-cycle current limit + hiccup protect the device); the ≥ 1.5 A
> recommendation is purely for full ruggedness against a hard short.

Candidate series (verify exact P/N, size and ratings against the requirements above): Coilcraft MSS-series /
XAL-series, Würth WE-LQS / WE-PD, Bourns SRR/SRN.

---

## 5. Output capacitor (C<sub>OUT</sub>)

**Selected: 22 µF / 25 V / X7R ceramic (ESR ≈ 5 mΩ).**

### 5.1 Steady-state ripple (Eq. 10 / Eq. 11)

```
ΔVOUT_C   = ΔiL / (8 × fSW × COUT) = 99.8 mA / (8 × 400 kHz × 22 µF) = 1.42 mV
ΔVOUT_ESR = ΔiL × ESR             = 99.8 mA × 5 mΩ                  = 0.50 mV
ΔVOUT(total) ≲ 2 mV   (the two terms are not in phase, so the real value is below their sum)
```

≈ 2 mV is **< 0.05 %** of 4.5 V — ripple is dominated by, and easily met by, a ceramic cap.

### 5.2 Load-transient limit (Eq. 12), full 0 → 200 mA step

```
COUT > ½ × 6 × (IOH − IOL) / (fSW × ΔVOUT_shoot)
  ΔVOUT_shoot = ±5 % (225 mV)  → COUT > 6.7 µF
  ΔVOUT_shoot = ±3 % (135 mV)  → COUT > 11.1 µF
```

A single **22 µF** part covers a full-load step to within ±3 % with margin, even after ceramic DC-bias
derating (a 25 V X7R at 4.5 V bias retains roughly 18–20 µF effective).

> A 10 µF / 25 V X7R is acceptable if minimizing size and only ±5 % transient is required.
> No load-transient spec was provided — values above assume a full 0 → 200 mA step; tighten C<sub>OUT</sub>
> if your overshoot/undershoot budget is smaller.

---

## 6. Input capacitor (C<sub>IN</sub>)

Datasheet §8.2.2.6: ≥ 2.2 µF ceramic, X7R/X5R, voltage rating **≥ 2 × V<sub>IN,max</sub>** = **≥ 80 V**.

| Component | Value | Rating | Notes |
|---|---|---|---|
| C<sub>IN</sub> (bulk decoupling) | **4.7 µF** (2.2 µF min) | **100 V**, X7R | 100 V rating gives ≥ 2× margin and offsets DC-bias derating of a 2.2 µF part |
| C<sub>IN_HF</sub> (high-freq bypass) | **0.1 µF** | 100 V, X7R | placed **directly** at the VIN/GND pins |

Input-cap RMS current:

```
ICIN,rms ≈ IOUT × √(D × (1 − D)) = 0.2 × √(0.1125 × 0.8875) = 63 mA
```

A 4.7 µF / 100 V X7R (1210) easily handles 63 mA.

> If the supply is more than a few inches from the device, add a bulk capacitor
> (10 µF or 22 µF electrolytic, ≥ 63 V) per datasheet §8.3.

---

## 7. Bootstrap capacitor (C<sub>B</sub> / C<sub>BOOT</sub>)

Fixed by the datasheet (§7.3.5, pin table): **0.1 µF (100 nF)** between **CB** and **SW**, X7R/X5R,
**≥ 16 V** rating.

| Component | Value | Rating | Notes |
|---|---|---|---|
| C<sub>BOOT</sub> | **0.1 µF (100 nF)** | 25 V, X7R | high-side gate-drive supply; abs-max CBOOT-to-SW is 5.5 V, so 25 V is ample |

---

## 8. Enable, soft-start & compensation

### 8.1 Enable / input UVLO — **EN tied directly to V<sub>IN</sub>**

No external divider. The converter then starts/stops on the device's **internal V<sub>IN</sub> UVLO**:

```
VIN UVLO rising  ≈ 3.82 V (typ),  max 4.0 V
VIN UVLO falling ≈ 3.56 V (typ),  min 3.4 V
Hysteresis       ≈ 0.25 V
```

At 40 V the device is always enabled. With EN = V<sub>IN</sub>, the EN pin sees 40 V, which is within both
the recommended range (0 to V<sub>IN</sub>) and the absolute maximum (V<sub>IN</sub> + 0.3 V). ✔

> A programmable turn-on threshold (e.g. start at 30 V / 36 V) would require an R<sub>ENT</sub>/R<sub>ENB</sub>
> divider (datasheet Eq. 13–15). Not used here per the chosen configuration.

### 8.2 Soft-start — **internal, fixed ≈ 2.3 ms** (no external component).
Also note: overcurrent-protection blanking time T<sub>OCP_BLK</sub> ≈ 33 ms at start-up, hiccup period ≈ 150 ms.

### 8.3 Loop compensation — **internal** (peak-current-mode, internally compensated). No external R/C network.

---

## 9. Protection, current limit & operating mode

| Item | Value | Comment |
|---|---|---|
| HS peak current limit, I<sub>HS_PK(OC)</sub> | 1.1 A typ (0.8 A min) | operating peak is 250 mA → **>3× margin**, no false trips |
| LS valley current limit, I<sub>LS_V(OC)</sub> | 0.8 A typ | — |
| Max deliverable current (Eq. 6) | (1.1 + 0.8)/2 = **0.95 A** | vs. 0.2 A required |
| Hiccup short-circuit protection | FB < 40 % V<sub>REF</sub> for 256 cycles | auto-recovering |
| Thermal shutdown | 165 °C (20 °C hyst.) | — |
| DCM/PFM boundary (this design) | I<sub>OUT</sub> ≈ ΔiL/2 = **50 mA** | above 50 mA → CCM; below → DCM/PFM |

**Mode behavior (PFM / "X" part):** at the rated 200 mA load the inductor current is continuous
(valley = 150 mA), so the converter operates in CCM near 400 kHz. At light loads it enters PFM (frequency
drops) for high efficiency, as selected.

> **Caveat:** because this is a low-current design, the full-load peak inductor current (~0.25 A) is close to
> the device's minimum PFM peak-current floor (I<sub>PEAK_MIN</sub> ≈ 0.33 A). Near and below full load the
> effective switching frequency may sit at or somewhat below 400 kHz, with correspondingly variable ripple.
> If a **guaranteed constant 400 kHz and minimum ripple at 200 mA** are required, use the pin-compatible
> **FPWM** variant **LMR51606XFDBVR** instead.

---

## 10. Efficiency & thermal estimate

From the datasheet efficiency curves (Fig. 6-3, 5 V / 400 kHz, interpolated to V<sub>IN</sub> ≈ 40 V,
I<sub>OUT</sub> = 0.2 A): **η ≈ 85 %**.

```
POUT  = 4.5 V × 0.2 A = 0.90 W
PLOSS = POUT/η − POUT ≈ 0.16 W   (of which inductor DCR ≈ 12 mW)
PIC   ≈ 0.15 W dissipated in the LMR51606
```

Junction-temperature rise in the SOT-23-6 (DBV):

```
ΔTJ = PIC × RθJA
    = 0.15 W × 95 °C/W  ≈ 14 °C   (good 2-layer layout, datasheet effective value)
    = 0.15 W × 147.8 °C/W ≈ 22 °C (JEDEC reference, minimal copper)
```

→ At T<sub>ambient</sub> = 85 °C, T<sub>J</sub> ≈ 99–107 °C — comfortably below the 150 °C limit. **No thermal concern.**

---

## 11. Bill of materials (BOM)

| Ref | Component | Value | Rating / Package | Notes |
|---|---|---|---|---|
| U1 | Buck converter | **LMR51606XDBVR** | SOT-23-6, 400 kHz, 0.6 A, PFM | TI |
| L1 | Power inductor | **100 µH** | I<sub>sat</sub> ≥ 1.5 A, I<sub>rms</sub> ≥ 0.3 A, DCR ≤ 0.3 Ω, shielded | SW → V<sub>OUT</sub> |
| C<sub>OUT</sub> | Output cap | **22 µF** | 25 V, X7R, ceramic | ~18–20 µF after DC-bias derate |
| C<sub>IN</sub> | Input cap | **4.7 µF** (≥ 2.2 µF) | 100 V, X7R, ceramic | bulk input decoupling |
| C<sub>IN_HF</sub> | Input HF bypass | **0.1 µF** | 100 V, X7R | right at VIN/GND pins |
| C<sub>BOOT</sub> | Bootstrap cap | **0.1 µF** | 25 V, X7R | CB → SW |
| R<sub>FBT</sub> | Feedback top | **75.0 kΩ** | 1 %, low-TC | V<sub>OUT</sub> → FB |
| R<sub>FBB</sub> | Feedback bottom | **16.2 kΩ** | 1 %, low-TC | FB → GND |
| — | EN | **wire to V<sub>IN</sub>** | — | no UVLO divider |
| C<sub>BULK</sub> *(optional)* | Bulk input cap | 10–22 µF | ≥ 63 V, electrolytic | only if supply is far from U1 |

---

## 12. Connection summary (per pin)

| Pin | Name | Connection |
|---|---|---|
| 1 | CB | C<sub>BOOT</sub> (0.1 µF) to SW (pin 6) |
| 2 | GND | System ground; ground side of C<sub>IN</sub>, C<sub>OUT</sub>, R<sub>FBB</sub> |
| 3 | FB | Junction of R<sub>FBT</sub> / R<sub>FBB</sub> |
| 4 | EN | Tied to VIN (pin 5) |
| 5 | VIN | 40 V input; C<sub>IN</sub> (4.7 µF) + C<sub>IN_HF</sub> (0.1 µF) to GND, directly at pin |
| 6 | SW | To L1 (100 µH); other end of L1 = V<sub>OUT</sub> (4.5 V) |

```
        VIN(40V) ───┬───────────────┬──────────┐
                    │               │          │
                  C_IN(4.7µF)    C_HF(0.1µF)    │
                    │               │           ├── VIN(5) ── EN(4)
                   GND             GND           │
                                                 │   CB(1) ──C_BOOT(0.1µF)──┐
                                                 │                          │
                                          [ LMR51606X ]   SW(6) ────────────┴──┬── L1(100µH) ──┬── VOUT(4.5V)
                                                 │                              │              │
                                                GND(2)                         (CB-SW cap)    R_FBT(75k)
                                                 │                                             │
                                                GND                              FB(3) ────────┤
                                                                                               R_FBB(16.2k)
                                                                                C_OUT(22µF)    │
                                                                                  │           GND
                                                                                 GND
```

---

## 13. Layout notes (datasheet §8.4)

1. Place **C<sub>IN</sub> / C<sub>IN_HF</sub> as close as possible to VIN and GND pins** — this is the #1 EMI driver
   (high di/dt loop).
2. Keep the **SW node copper small** but thick enough for the load current; keep the SW–L1 trace short.
3. Place **C<sub>BOOT</sub> close to CB and SW pins**.
4. Place **R<sub>FBT</sub>/R<sub>FBB</sub> next to the FB pin**; route the FB/V<sub>OUT</sub>-sense trace away from
   the SW node and inductor (FB is a high-impedance node). Sense V<sub>OUT</sub> at the load if accuracy matters.
5. Use a **solid ground plane**; connect the IC GND and C<sub>IN</sub>/C<sub>OUT</sub> grounds to it with short
   paths and use thermal vias under/around the device to spread heat and keep T<sub>J</sub> < 125 °C.

---

## 14. Assumptions

- V<sub>IN</sub> = 40 V treated as the maximum operating input (worst case for ripple current).
- Inductor ripple ratio K<sub>IND</sub> = 0.5 (chosen for a smaller ~100 µH inductor; more ripple accepted).
- EN tied directly to V<sub>IN</sub>; turn-on/off governed by the internal V<sub>IN</sub> UVLO (≈ 3.8 V / 3.56 V).
- PFM (auto-mode) part selected → LMR51606XDBVR.
- Load-transient analysis assumes a full 0 → 200 mA step (no explicit transient spec was given).
- Efficiency ≈ 85 % read/interpolated from the datasheet curves; T<sub>J</sub> rise computed for both the 2-layer
  effective and JEDEC R<sub>θJA</sub> values.

*Reference: Texas Instruments LMR51606 / LMR51610 datasheet, SLUSEY1B (Dec 2023) — `lmr51606.pdf` in this folder.*

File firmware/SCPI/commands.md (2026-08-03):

# SCPI Command Reference — 2-Channel Bench Power Supply

Remote-control command set for the power supply. Commands are sent from a PC to
the PSU over **USB (CDC-ACM / USB-TMC)** or **Ethernet (raw TCP, port 5025 —
the SCPI "instrument" port)**. Both transports address the same command parser
on the **Brain** (RP2350), which translates every command into the binary UART
protocol spoken to each **Channel** (ATtiny1614). See
`firmware/channel/include/protocol.h` for that lower layer.

The instrument aims to be a well-behaved **SCPI-1999 / IEEE-488.2** subset so it
works with VISA, PyVISA, `lxi`, NI-MAX, and generic terminal tools.

> **Implementation status (firmware ≥ 0.2.0):** this command set is implemented in
> `firmware/brain/main/src/scpi.cpp`, served over both the **W5500 Ethernet** TCP
> socket (port 5025) and the **USB CDC** console. LAN configuration lives in the
> front-panel *Settings → Network* submenu (`netcfg.cpp`). Known deviations:
> voltage setpoints resolve to 10 mV (the panel's finest digit) rather than 1 mV;
> `CALibration:DATA?` returns SCPI NaN because gain/offset cannot be read back over
> the channel link; and `SYSTem:COMMunicate:LAN:HOSTname` is stored/displayed but,
> with the stock Ethernet DHCP client, is not advertised as the DHCP host name. The
> real per-channel limits are **36.000 V / 2.000 A** (see `config.h`), so `*IDN?`
> reports model `PSU-2CH-36V2A`.

---

## 1. Instrument model

| Property | Value |
|---|---|
| Channels | 2 (CH1, CH2) — independent, isolated |
| Output voltage | 0 … 36.000 V per channel |
| Output current limit | 0 … 2.000 A per channel |
| Setpoint resolution | 1 mV / 1 mA (protocol carries int32 mV / mA) |
| Measurement | V, I, P (V·I) per channel; one system temperature |
| Temperature | Highest of the Brain sensor and both Channel sensors |
| Regulation | CV / current-limited output; the firmware does **not** report which mode is active |
| Protection | Over-temperature only (hardware OTP, ≥60 °C per channel). No OVP/OCP. |
| Calibration | 2-point linear, 4 paths per channel, stored in EEPROM |

> **Firmware note:** the setpoint clamps in `firmware/channel/include/config.h`
> (`SETPOINT_V_MAX_MV`, `SETPOINT_I_MAX_MA`) must match these limits — set them
> to `36000` and `2000` respectively.

---

## 2. Syntax conventions

- Commands are **case-insensitive**. Upper-case letters show the accepted short
  form; lower-case letters are optional (`VOLTage` ⇒ `VOLT` or `VOLTAGE`).
- A command **line** is terminated by `\n` (LF). `\r` is ignored. Max line
  length 256 bytes.
- Multiple commands may be **chained** with `;` on one line. A leading `:` after
  `;` restarts from the root (`:VOLT 5;:CURR 1`).
- **Queries** end in `?` and return a single line terminated by `\n`.
- Numeric parameters accept decimals and SI suffixes/multipliers
  (`2.5`, `2500m`, `2.5V`). Booleans accept `ON|OFF|1|0`.
- `MIN | MAX | DEF` may be used anywhere a numeric value is expected, and as a
  query argument (`VOLT? MAX`).
- **Channel selection** — two equivalent styles are supported:
  - *Stateful:* select with `INSTrument:NSELect <n>`; subsequent SOURce/MEASure
    commands act on that channel.
  - *Per-command channel list:* append `(@<list>)`, e.g. `(@1)`, `(@2)`,
    `(@1,2)`. A channel list overrides the selected channel for that command
    only. Queries with `(@1,2)` return comma-separated values, CH1 first.

Notation below: `<n>` = channel 1|2, `<NRf>` = flexible numeric, `<bool>` =
ON|OFF|1|0, `[]` = optional node, `{a|b}` = choice.

---

## 3. IEEE-488.2 common commands

| Command | Action |
|---|---|
| `*IDN?` | Identify. Returns `Manufacturer,Model,Serial,FW-version` e.g. `PreReg,PSU-2CH-36V2A,SN00001,0.2.0` |
| `*RST`  | Reset to default state: both outputs **OFF**, V=0, I limit=MAX, protections cleared. Maps to `SET_OUTPUT 0` on both channels. |
| `*CLS`  | Clear status: error queue, Standard Event (ESR) and Questionable/Operation event registers. |
| `*ESE <NRf>` / `*ESE?` | Set/query Standard Event Status **Enable** mask. |
| `*ESR?` | Read & clear Standard Event Status register. |
| `*SRE <NRf>` / `*SRE?` | Set/query Service Request Enable mask. |
| `*STB?` | Read Status Byte (does not clear). |
| `*OPC` / `*OPC?` | Operation complete. `*OPC?` returns `1` when all pending overlapped commands finish. All commands here are sequential, so `*OPC?` returns `1` immediately. |
| `*WAI` | Wait for pending operations (no-op; sequential execution). |
| `*TST?` | Run/report power-on **self-test**. Returns `0` = pass, non-zero = fault bitmask (see §10). Re-runs the Channel `SELFTEST` state. |
| `*SAV {0..3}` | Save current setpoints/output state to instrument memory slot. |
| `*RCL {0..3}` | Recall a saved slot. |

---

## 4. INSTrument — channel selection

| Command | Description |
|---|---|
| `INSTrument[:SELect] {CH1|CH2}` | Select the active channel by name. |
| `INSTrument:NSELect <n>` / `?` | Select/query active channel by number (1\|2). |
| `INSTrument[:SELect]?` | Query active channel name. |
| `INSTrument:CATalog?` | List available channels → `CH1,CH2`. |

---

## 5. SOURce subsystem (setpoints & protection)

The `SOURce:` root node is optional and usually omitted. Commands act on the
selected channel unless a `(@<list>)` suffix is given.

### 5.1 Voltage

| Command | Description | UART mapping |
|---|---|---|
| `[SOURce:]VOLTage[:LEVel][:IMMediate][:AMPLitude] <NRf>[,(@list)]` | Set output voltage (V). | `CMD_SET_VOLTAGE` (int32 mV) |
| `[SOURce:]VOLTage? [{MIN\|MAX\|DEF}][,(@list)]` | Query voltage **setpoint**. | — |

### 5.2 Current (current limit)

The current setpoint **is** the current limit — the channel holds this current
when the load demands it. The firmware does not report a CV/CC mode flag, so
there is no query for the active regulation mode.

| Command | Description | UART mapping |
|---|---|---|
| `[SOURce:]CURRent[:LEVel][:IMMediate][:AMPLitude] <NRf>[,(@list)]` | Set current limit (A). | `CMD_SET_CURRENT` (int32 mA) |
| `[SOURce:]CURRent? [{MIN\|MAX\|DEF}][,(@list)]` | Query current setpoint. |

> **Protection:** the only protection is the Channel's autonomous
> over-**temperature** shutdown (≥60 °C, `EVT_OVERTEMP`). It cannot be enabled,
> disabled, or configured remotely. There is **no** OVP or OCP — the current
> setpoint is a simple current limit, nothing more.

### 5.3 Combined apply (convenience)

| Command | Description |
|---|---|
| `APPLy {CH1\|CH2},<volt>,<curr>` | Set voltage and current in one call. |
| `APPLy? [{CH1\|CH2}]` | Query as `<volt>,<curr>`. |

---

## 6. OUTPut subsystem

| Command | Description | UART mapping |
|---|---|---|
| `OUTPut[:STATe] <bool>[,(@list)]` | Enable/disable output. On enable the Channel runs its DCDC→linear sequence (`IDLE→RUN`). | `CMD_SET_OUTPUT` (u8 0/1) |
| `OUTPut[:STATe]? [(@list)]` | Query output state → `0`/`1`. | telemetry `FLAG_OUTPUT_ON` |
| `OUTPut:PROTection:CLEar[,(@list)]` | Clear a latched over-temperature `FAULT` on the channel (once cooled). | `CMD_RESET_FAULT` |

> There is no `OUTPut:MODE?` query — the firmware does not distinguish CV from
> current-limited operation, so the active regulation mode is not observable.

`OUTPut:STATe` refuses to turn on a channel that is in `FAULT` or reports
`FLAG_CAL_INVALID` as a hard error (see §10) unless overridden — bring the
channel out of fault first with `OUTP:PROT:CLE`.

---

## 7. MEASure / FETCh (readback)

`MEASure:...?` returns the most recent telemetry (the Channel pushes telemetry
every 100 ms; the Brain caches it and may force a fresh `CMD_GET_STATUS`).
`FETCh:...?` returns the cached value without forcing a poll.

| Query | Returns | Telemetry field |
|---|---|---|
| `MEASure[:SCALar]:VOLTage[:DC]? [(@list)]` | Measured output voltage (V) | `v_mV` |
| `MEASure[:SCALar]:CURRent[:DC]? [(@list)]` | Measured output current (A) | `i_dmA` |
| `MEASure[:SCALar]:POWer[:DC]? [(@list)]` | Measured output power (W) | `p_mW` |
| `MEASure:TEMPerature?` | **System** temperature (°C) — the highest of the Brain sensor and both Channel `temp_cC` readings | max of all |
| `MEASure:ALL? [(@list)]` | `V,I,P` comma-separated (per channel) | frame |
| `FETCh:VOLTage? / :CURRent? / :POWer? / :ALL?` | Cached equivalents | — |

`MEASure:TEMPerature?` takes **no** channel list — it is a single instrument
value (the hottest of Brain + CH1 + CH2), which is also what drives OTP
reporting. For `(@1,2)` a scalar V/I/P query returns `ch1,ch2`; `MEAS:ALL?
(@1,2)` returns `v1,i1,p1,v2,i2,p2`.

**Numeric format:** measured **voltage** is returned with **3** decimal places
(1 mV resolution, e.g. `12.001`) and measured **current** with **4** decimal
places (0.1 mA resolution, e.g. `0.2531`), matching the front-panel readout.

---

## 8. STATus subsystem (SCPI status model)

The instrument maps Channel telemetry flags/state into the SCPI Questionable
and Operation status registers.

| Command | Description |
|---|---|
| `STATus:QUEStionable[:EVENt]?` | Read & clear Questionable event register. |
| `STATus:QUEStionable:CONDition?` | Read live Questionable condition. |
| `STATus:QUEStionable:ENABle <NRf>` / `?` | Enable mask. |
| `STATus:OPERation[:EVENt]?` / `:CONDition?` / `:ENABle` | Operation register set. |
| `STATus:PRESet` | Set enable masks to default. |

**Questionable-status bit assignment (per channel, OR'd into the summary):**

| Bit | Weight | Meaning | Source |
|-----|---|---|---|
| 4 | 16  | Over-temperature | `FLAG_OVERTEMP` / `EVT_OVERTEMP` |
| 8 | 256 | Calibration invalid | `FLAG_CAL_INVALID` |
| 9 | 512 | ADC fault | `FLAG_ADC_FAULT` |
| 10| 1024| DAC fault | `FLAG_DAC_FAULT` |
| 11| 2048| Channel in FAULT state | `ST_FAULT` |

**Operation-status bits:** bit 8 (256) = CH1 output ON, bit 9 (512) = CH2 output
ON (`FLAG_OUTPUT_ON`). The firmware exposes no CV/CC mode flag, so there is no
constant-current status bit.

---

## 9. SYSTem subsystem

| Command | Description |
|---|---|
| `SYSTem:ERRor[:NEXT]?` | Pop oldest entry from the error queue → `<code>,"<message>"`. `0,"No error"` when empty. |
| `SYSTem:ERRor:COUNt?` | Number of queued errors. |
| `SYSTem:VERSion?` | SCPI version → `1999.0`. |
| `SYSTem:CHANnel:COUNt?` | Number of channels → `2`. |
| `SYSTem:BEEPer[:IMMediate]` | Sound the panel buzzer once. |
| `SYSTem:BEEPer:STATe <bool>` / `?` | Enable/disable UI beeps. |
| `SYSTem:LOCal` / `SYSTem:REMote` / `SYSTem:RWLock` | Local / remote / remote-with-lockout front-panel control. |
| `SYSTem:COMMunicate:LAN:IPADdress <ip>` / `?` | Static IP (Ethernet). |
| `SYSTem:COMMunicate:LAN:DHCP <bool>` / `?` | Enable DHCP. |
| `SYSTem:COMMunicate:LAN:MAC?` | MAC address. |
| `SYSTem:UPTime?` | Seconds since boot. |

---

## 10. CALibration subsystem

Exposes the Channel's 2-point linear calibration (`y = gain·x + offset`) for all
four signal paths. Requires unlocking with a code to prevent accidental changes.
Maps to `CMD_CAL_POINT`, `CMD_CAL_COMMIT`, `CMD_CAL_RESET`.

Path selector `<path>` = `VSET | ISET | VMEAS | IMEAS`
(→ `CAL_VSET/ISET/VMEAS/IMEAS`).

| Command | Description | UART mapping |
|---|---|---|
| `CALibration:STATe <bool>,<code>` | Unlock/lock calibration (default code `0`). | — |
| `CALibration:STATe?` | `1` if unlocked. | — |
| `CALibration:POINt <path>,{0\|1},<actual>` | Record a cal point: index 0 = low, 1 = high; `<actual>` = externally measured true value (V or A). | `CMD_CAL_POINT{target,index,actual}` |
| `CALibration:COMMit <path>` | Solve the line from the two points and persist to EEPROM. | `CMD_CAL_COMMIT{target}` → `EVT_CAL_STORED`/`EVT_CAL_INVALID` |
| `CALibration:RESet <path>` | Restore compile-time default gain/offset. | `CMD_CAL_RESET{target}` |
| `CALibration:DATA? <path>` | Query stored `gain,offset` for a path. | — |
| `CALibration:VALid? [(@list)]` | `1` if all paths calibrated (not `FLAG_CAL_INVALID`). | telemetry flag |

**Typical procedure (per channel, VSET example):**
```
INST:NSEL 1
CAL:STAT ON,0
VOLT 5.0            ; drive a low point
CAL:POIN VSET,0,4.987   ; report DMM reading
VOLT 25.0           ; drive a high point
CAL:POIN VSET,1,24.912
CAL:COMM VSET       ; solve & store
CAL:STAT OFF,0
```

---

## 11. Error / status codes

Standard SCPI error queue (negative = SCPI-defined, positive = device-specific):

| Code | Message | Cause |
|---|---|---|
| `0` | No error | queue empty |
| `-100` | Command error | unrecognized command header |
| `-108` | Parameter not allowed | too many parameters |
| `-109` | Missing parameter | too few parameters |
| `-113` | Undefined header | unknown command |
| `-120` | Numeric data error | malformed number |
| `-222` | Data out of range | value clamped to MIN/MAX (e.g. V>36, I>2) |
| `-241` | Hardware missing | channel not responding on UART |
| `-315` | Configuration memory lost | EEPROM cal CRC bad |
| `+101` | Channel self-test failed | `EVT_SELFTEST_FAIL` |
| `+102` | Over-temperature | `EVT_OVERTEMP` (output forced off) |
| `+103` | ADC fault | `EVT_ADC_FAULT` |
| `+104` | DAC fault | `EVT_DAC_FAULT` |
| `+105` | Calibration invalid | `EVT_CAL_INVALID` / `FLAG_CAL_INVALID` |
| `+106` | Output enable refused | channel in FAULT / cal invalid |
| `+107` | UART CRC / framing error | link error to a channel |

`*TST?` fault bitmask (bit set = failed): b0 CH1 comms, b1 CH1 selftest,
b2 CH2 comms, b3 CH2 selftest, b4 any over-temp at boot.

---

## 12. Brain ↔ Channel mapping summary

| SCPI action | UART command (per channel) |
|---|---|
| `VOLT <v>` | `CMD_SET_VOLTAGE` (int32 mV) |
| `CURR <i>` | `CMD_SET_CURRENT` (int32 mA) |
| `OUTP ON/OFF` | `CMD_SET_OUTPUT` (u8) |
| `MEAS:*?`, `FETC:*?` | cached `CMD_TELEMETRY`, or `CMD_GET_STATUS` poll |
| `OUTP:PROT:CLE`, `*RST` fault clear | `CMD_RESET_FAULT` |
| `CAL:POIN` | `CMD_CAL_POINT` |
| `CAL:COMM` | `CMD_CAL_COMMIT` |
| `CAL:RES` | `CMD_CAL_RESET` |
| connectivity check | `CMD_PING` → `CMD_ACK` |

Async Channel `CMD_EVENT` frames (BOOT, OVERTEMP, faults, cal-stored) are
converted by the Brain into error-queue entries and Questionable-status bits,
so the host sees them via `SYST:ERR?` / `STAT:QUES?` and, if enabled, an SRQ.

---

## 13. Worked examples

**Basic setup — 12 V, 1 A limit on CH1, read back:**
```
*RST
INST:NSEL 1
APPL CH1,12.0,1.0
OUTP ON
MEAS:VOLT?      ; -> 12.001
MEAS:CURR?      ; -> 0.2531
MEAS:POW?       ; -> 3.036
```

**Both channels at once via channel list:**
```
VOLT 5.0,(@1,2)
CURR 2.0,(@1,2)
OUTP ON,(@1,2)
MEAS:ALL? (@1,2)   ; -> v1,i1,p1,v2,i2,p2
MEAS:TEMP?         ; -> 41.2   (hottest of brain + both channels)
```

**Recover a channel after an over-temperature shutdown:**
```
STAT:QUES:COND?    ; bit4 (16) set -> over-temperature
OUTP:PROT:CLE (@1) ; clears the FAULT once cooled below re-arm temp
OUTP ON (@1)
```

**Poll for errors (PyVISA idiom):**
```
while True:
    code, msg = psu.query("SYST:ERR?").split(",", 1)
    if int(code) == 0: break
    log(code, msg)
```

---

*Implementation note:* this document is the **specification** for the SCPI layer
that runs on the Brain (RP2350). The parser should be table-driven (header tree +
handler), keep a per-session error queue, and translate every accepted command
into the binary UART frames defined in `firmware/channel/include/protocol.h`.
Values are clamped to the Channel limits (`SETPOINT_V_MAX_MV`,
`SETPOINT_I_MAX_MA`) with a `-222` warning rather than being rejected.

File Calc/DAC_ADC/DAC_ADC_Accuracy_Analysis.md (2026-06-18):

# DAC / ADC Accuracy Analysis — 2-Channel Pre-Reg Power Supply

**Date:** 2026-06-18
**Scope:** Setpoint (DAC) and measurement (ADC) accuracy of one channel, including the analog sense/scaling network that feeds them.
**Sources:** `schaltplan.pdf` sheet 8 (`DAC_ADC.kicad_sch`) and sheet 10 (`Linear_PostReg.kicad_sch`); datasheets `20005466A.pdf` (MCP48FVBxx), `20005440A.pdf` (MCP48FxBxx curves), `ads1118.pdf`, `tlv2387 (1).pdf`.

> **Headline:** The silicon can *measure* to ~14 bits (≈1.8 mV / 0.10 mA) and *set* to 12 bits (≈8.6 mV / 0.49 mA). Uncalibrated absolute accuracy is poor (~±3–4 %), dominated by the DAC internal band gap (±3.3 %) and 1 % resistors/shunt. **A multimeter-based 2-point calibration is mandatory** and removes all of that, leaving a temperature/INL/noise floor of ~±0.05 % (V) and ~±0.1–0.2 % (I).

---

## 1. Circuit as drawn

### 1.1 DAC/ADC sheet (sheet 8, `DAC_ADC.kicad_sch`)

| Device | Part | Configuration |
|---|---|---|
| **DAC** | U702 = **MCP48FVB22** | 12-bit dual, VDD = +3V3. Outputs **VA→Vset**, **VB→Iset**. SPI. `LAT/HVC`←DAC_LATCH. |
| **ADC** | U701 = **ADS1118IDGS** | 16-bit ΔΣ, VDD = +3V3. **Vsense→AIN0**, **Isense→AIN2**; AIN1/AIN3→GND (two pseudo-differential single-ended measurements). SPI. |

**Critical finding — DAC reference:** the **Vref pin (3) is left unconnected**. The DAC therefore must use the **internal 1.22 V band gap** (×2 output buffer → **2.44 V full scale**) or VDD as reference. *Decision (confirmed): internal band gap is used.* The unrouted Vref pin forecloses using an external precision reference without a board change.

**ADC input filters R701/R702/C701/C702 are unpopulated ("##").**

### 1.2 Sense / scaling network (sheet 10, `Linear_PostReg.kicad_sch`)

| Path | Topology | Resistors | Gain | Full-scale |
|---|---|---|---|---|
| **Voltage sense** (U501D, TLV4387) | **4-resistor difference amp** across OUT+ / OUT− | R313, R314 = 62k (inputs); R306, R309 = 4.3k (fb/gnd) | 4.3k/62k = **0.06935** | 36 V → 2.4957 V |
| **Current sense** (U501C, TLV4387) | **non-inverting** amp on low-side shunt | R318 = 0.1 Ω shunt; R316 = 18k, R317 = 1.6k | 0.1 Ω × (1+18k/1.6k) = **×12.25** | 2 A → 2.45 V |

The voltage sense amp sees a **common-mode voltage ≈ Vout/2 (up to ~18 V)**, so its four resistors' *matching* sets CMRR. The current sense is referenced to GND (no CMRR concern). The shunt (PCS2512, 0.1 Ω, "F" = ±1 %) dissipates **0.4 W at 2 A**.

---

## 2. System scaling (confirmed full-scale: 36 V / 2 A)

| | Factor | DAC FS (2.44 V) maps to | ADC usable (2.5 V) maps to |
|---|---|---|---|
| Voltage | 0.06935 V_adc/V_out → ×14.42 V_out/V_adc | 35.2 V | 36.0 V |
| Current | 1.225 V_adc/A_out → ÷1.225 | 1.99 A | 2.04 A |

---

## 3. Key datasheet specs

### 3.1 MCP48FVB22 DAC (band gap, G=0, 12-bit) — `20005466A.pdf`
| Parameter | Typ | Max | Note |
|---|---|---|---|
| Resolution | 12-bit / 4096 taps | — | no missing codes |
| **Internal band gap V_BG** | 1.22 V | 1.18–1.26 V = **±3.3 %** | dominant uncalibrated error |
| Output FS (×2 buffer) | 2.44 V | — | LSB = 595.7 µV |
| Offset error | ±1.5 mV | ±15 mV | G=0 |
| Offset tempco | ±10 µV/°C | — | |
| Gain error (ext-ref basis) | ±0.1 % | ±1.0 % | band gap tol adds on top |
| Gain-error drift | −3 ppm/°C | — | |
| **V_OUT tempco (midscale)** | **15 ppm/°C** | — | practical output drift |
| INL (band gap mode) | ≈ ±2 LSb | — | from curves doc p14 |
| DNL | small, monotonic | — | guaranteed no missing codes |

### 3.2 ADS1118 ADC — `ads1118.pdf`
| Parameter | Typ | Max | Note |
|---|---|---|---|
| Resolution | 16-bit | — | no missing codes |
| **Required FSR for 0–2.5 V** | **±4.096 V** | — | 2.5 V > 2.048 V → next range up; **LSB = 125 µV** |
| Effective bits over 0–2.5 V | ~14.3 | — | only ~20000 of 65536 codes used |
| INL | — | 1 LSb | best-fit, 99 % FS |
| Offset error (single-ended) | ±0.25 LSb | — | drift 0.002 LSb/°C |
| **Gain error (incl. PGA + ref)** | ±0.01 % | **±0.15 %** | internal ref error included |
| Gain drift (incl. ref) | 7 ppm/°C | 40 ppm/°C | |
| Noise @ 8 SPS, ±4.096 V | ≈1 LSb RMS | — | quantization-limited; ~16-bit ENOB over full ±FSR |

---

## 4. Resolution (the hard floor)

| | DAC setpoint (12-bit, 2.44 V) | ADC measurement (±4.096 V FSR) |
|---|---|---|
| Step at chip | 595.7 µV | 125 µV |
| **Voltage** | **8.6 mV** (0.024 % FS) | **1.8 mV** (0.005 % FS) |
| **Current** | **0.49 mA** (0.024 % FS) | **0.10 mA** (0.005 % FS) |
| Effective bits | 12.0 | ~14.3 |

➡ **Measurement is ~5× finer than setpoint.** You can read finer than you can command.

---

## 5. Accuracy budget — uncalibrated vs. calibrated

| Error source | Uncalibrated | After multimeter 2-pt cal |
|---|---|---|
| DAC band gap tol (1.18–1.26 V) | **±3.3 %** | removed |
| DAC gain / offset | ±1 % / ±15 mV | removed |
| ADC gain error (incl. ref) | ±0.15 % | removed |
| Resistor divider tol (1 %) | ±1.4 % | removed |
| Shunt tol (±1 %) | ±1 % (I) | removed |
| DAC INL + ADC INL | included | ~±1.8 mV (V) / ~±0.1 mA (I) |
| Temp drift (band gap/V_OUT 15 ppm/°C, ADC 7–40 ppm/°C, resistor & shunt TCR) | — | dominant residual |
| ADC noise @ 8 SPS | ~1 LSb | ~1 LSb (averages out) |
| **Net** | **~±3–4 %** | **~±0.05 % (V), ~±0.1–0.2 % (I)** |

Calibration removes every *absolute* term. What survives = **INL + noise + drift from cal point**.

---

## 6. Tolerance recommendation — per location

> **Because you calibrate, absolute tolerance is nearly irrelevant — use 1 % initial value almost everywhere.** Spend the budget on **TCR**, **matching** (V-sense diff-amp), and **shunt self-heating**.

| Ref | Value | Role | Absolute | **TCR** | **Matching** | Suggested part |
|---|---|---|---|---|---|---|
| **R313, R314** | 62k | V-sense diff-amp inputs (OUT+/OUT−) | 1 % OK | ≤10–25 ppm/°C | **critical (CMRR)** | thin-film, matched |
| **R306, R309** | 4.3k | V-sense diff-amp fb/gnd | 1 % OK | ≤10–25 ppm/°C | **critical (ratio tracks R313/R314)** | thin-film, matched |
| → all four | | set V gain **and** CMRR | | **best: single matched network, tracking ≤5 ppm/°C, ratio match ≤0.1 %** | | 4-element divider array |
| **R318** | 0.1 Ω | current shunt | ≤0.5 % | **≤50 ppm/°C (critical), ≤25 better** | n/a | 4-terminal/Kelvin metal-foil, **≥1 W headroom** |
| **R316, R317** | 18k / 1.6k | I-sense amp gain (×12.25) | 1 % OK | ≤25 ppm/°C | ratio only (0.1 % pair) | thin-film pair |
| R301–R305 | 1k–10k | CV/CC loop summing | 1 % OK | not critical *if closed-loop setpoint* | matched only if open-loop | std 1 % |
| R701, R702 | ~1k (populate) | ADC anti-alias R | 1 % OK | not critical | — | std 1 % (≤1 kΩ) |
| C701, C702 | ~100n (populate) | ADC anti-alias C | — | **C0G/NP0** | — | NP0 |
| C703, C704 | 100n | decoupling | — | — | — | X7R |

**Why V-sense matching dominates:** the diff-amp rejects ≤18 V common mode. At 1 % resistors, worst-case CMRR ≈ 28 dB → ~0.67 V CM-induced gain error. Cal absorbs the static part, but **differential TCR re-introduces it**: uncorrelated 25 ppm/°C → ~±36 mV/20 °C at 36 V; a matched network (≤5 ppm/°C tracking) → <5 mV. Matching/tracking — not absolute value — is the real V-accuracy lever.

**Why shunt TCR/self-heating:** 0.4 W at 2 A → load-dependent self-heating that **cannot be calibrated out** (it varies with current). A 2512 (~1 W) at 50 ppm/°C gives a few mA drift. Kelvin foil shunt with ≥2× power margin and ≤25 ppm/°C removes most of it.

---

## 7. Achievable accuracy (band gap + multimeter cal, recommended parts, 36 V / 2 A)

| | Resolution | After cal @ fixed temp | Over 0–50 °C |
|---|---|---|---|
| **V setpoint** | 8.6 mV | ≈ measurement (closed-loop) | ±0.05 % + few mV |
| **V measurement** | 1.8 mV | ±2–3 mV | ~±15–20 mV (~±0.05 %), diff-amp tracking-limited |
| **I setpoint** | 0.49 mA | ≈ measurement (closed-loop) | ±0.1 % |
| **I measurement** | 0.10 mA | ±2–3 mA | ±0.1–0.2 %, shunt-limited |

---

## 8. Recommendations / action items

1. **Closed-loop setpoint in firmware** (set DAC → read ADC → trim to target). Servos out the DAC band gap error, DAC INL, and the CV/CC loop resistor ratios → setpoint accuracy becomes *measurement* accuracy, limited only by the 8.6 mV / 0.49 mA DAC step. (This is why R301–R305 can stay 1 %.)
2. **Buy tolerance only where it counts:** a matched 4-resistor network for R313/R314/R306/R309, and a low-TCR Kelvin shunt for R318. Everything else 1 %.
3. **Populate the ADC input filters** R701/C701 & R702/C702 (≈1 kΩ + 100 nF NP0, ~1.6 kHz). Keep series R ≤1 kΩ (ADC Z_in ≈15 MΩ → ~67 ppm loading, calibrates out).
4. **Shunt:** size for ≥2× power margin or use a dedicated current-sense element; the 0.4 W self-heating is the current channel's accuracy limit.
5. **Grounding:** the pseudo-differential ADC inputs (AIN1/AIN3 = GND) make any sense-ground IR drop a direct error — Kelvin the ADC analog ground to the sense reference.
6. **Run the ADC at 8 SPS** (or average) for ~16-bit ENOB / lowest noise; trade against update rate.

### Optional improvement — reclaim ADC resolution
The ADC is forced to ±4.096 V because the sense maxes at ~2.5 V (>2.048 V), wasting ~0.7 bit. **Rescaling both sense paths to ≤2.0 V max** lets the ADC use **±2.048 V FSR → 62.5 µV LSB**, doubling measurement resolution to **~0.9 mV / 0.05 mA (~15 bit)**. Requires changing the divider/gain resistors (and watch headroom so transients don't clip the 2.048 V range).

---

## 9. Open items / assumptions

- **Confirmed:** internal band gap reference; firmware multimeter calibration; 36 V / 2 A full scale.
- **Assumed:** firmware does *closed-loop* setpoint (recommended). If open-loop, R301–R305 ratios need 0.1 %.
- DAC INL taken as ≈±2 LSb (band gap mode) from `20005440A.pdf` p14 (typical curves; not a guaranteed limit).
- Resistor/shunt tolerances are **not specified in the schematic** — assumed 1 % unless changed per §6.

---

## Appendix — key formulas

```
DAC LSB            = 2.44 V / 4096                = 595.7 µV
ADC LSB (±4.096 V) = 4.096 V / 32768              = 125 µV
V scale            = R306/R313 = 4.3k/62k         = 0.06935  (×14.42 to output)
I scale            = R318·(1+R316/R317)=0.1·12.25 = 1.225 V/A
Diff-amp CMRR (tol t) ≈ (1 + Rf/Rin) / (4·t)
ENOB               = ln(FSR / V_RMS_noise) / ln(2)
```

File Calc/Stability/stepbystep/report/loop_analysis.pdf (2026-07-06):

# Stability Analysis of the CV and CC Control Loops

2-Channel Pre-Regulated Power Supply — study loops (simple loops.kicad_sch, sheets V_loop and I_loop)

Companion document to V_loop_transfer_functions.ipynb and I_loop_transfer_functions.ipynb — 2026-07-06

## 1 Overview and method

Both regulator loops share the same four-block structure (Figure 1): an op-amp error amplifier with a frequency-shaping feedback network (the compensator), a driver + pass stage (small NPN driving a TIP125 PNP Darlington), an output network, and a sense amplifier that scales the regulated quantity back to the error amp.

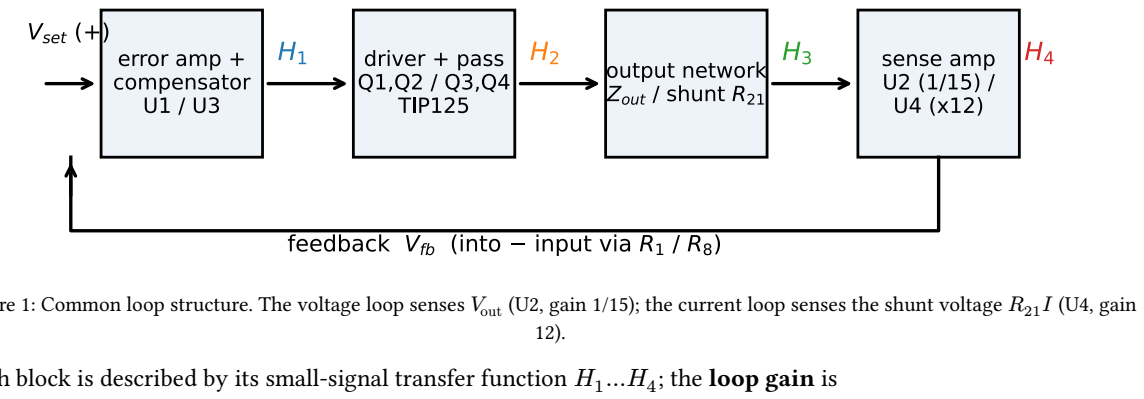
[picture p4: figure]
I (U4, gain; ; the loop gain is

Figure 1: Common loop structure. The voltage loop senses Vout (U2, gain 1/15); the current loop senses the shunt voltage R21

Each block is described by its small-signal transfer function H1…H4

T (s) = H1

(s) H2

(s) H3

(s) H4

(s).

The error amp is inverting for the fed-back signal, which supplies the 180° that makes the feedback negative; stability is then read from the frequency shaping of T :

- crossover fc
: the frequency where |T | = 1 (0 dB);
- phase margin PM = 180° + ∠T (j2πfc

) — distance from oscillation;
- gain margin GM = −|T |dB where ∠T = −180°;
- sensitivity peak Spk = max|1/(1 + T )| — a single robustness number (Spk < 1.5: well damped; Spk > 2: pronounced ringing).

Because several parameters are uncertain in reality, every design is evaluated over corners, not just nominal values: the TIP125 gain spread (β0 = 500…4000), its frequency derating at low bias current, and (for the V loop) the load impedance and the output-capacitor ESR.

## 2 Device data used in the models

Op-amps (U1–U4): gain-bandwidth product GBW = 5.7 MHz, slew rate 2.8 V/µs. The open-loop gain is modelled as a dominant-pole integrator A(s) = 2π ⋅ GBW /s and enters the compensator exactly through the noise-gain form (Section 3.1). Slew rate is a large-signal limit and does not appear in the AC model.

TIP125 PNP Darlington (Q2/Q4): the datasheet’s small-signal current gain (Fig. 7, PNP @ 3 A) is fitted by a two-pole roll-off,

β(s) =

β0
(1 + s/ωβ1

)(1 + s/ωβ2

)

, fβ1 ≈ 60 kHz, fβ2 ≈ 300 kHz,

which reproduces the curve well (Figure 2). This roll-off — not the op-amp — is the dominant high-frequency dynamic of both loops. Two spreads are swept as corners:

- β0
: datasheet minimum 1000, typical 2000–4000 (DC gain, Fig. 9); 500 is added as cold/low-current pessimism. Loop gain scales 1:1 with β0
, so the crossover slides almost a decade across production spread.

- Low-bias derating: Fig. 7 is specified at 3 A. At small collector current fT

drops, so a derated corner with fβ1,2 = 20/100 kHz is checked (“LB” in the tables).

Minimum-load current sink (≈ 12 mA). The production hardware places a constant-current sink on each output (BCP56 Q304, diode bias D1006, 47 Ω degeneration R320), connected so that it bypasses the current shunt. The pass transistor therefore never idles below ≈ 12 mA — without it, only the 1 mA sense-divider current flows at no load, and nothing bounds how far fβ

collapses. Small-signal the sink is high-impedance (≳ 100 kΩ), so it does not change any load case; its benefit is bias: the LB corner becomes a guaranteed pessimistic floor instead of an open-ended assumption, and if 12 mA is enough to hold the Fig.-7 poles, the LB corner does not apply at all. The tables below report the worst case both ways. Because the sink bypasses the shunt, the current loop sees no 12 mA offset — CC regulates the true load current and setpoints below 12 mA remain usable; the pass device also never cuts off at no load, and the sink provides 12 mA of down-programming current.

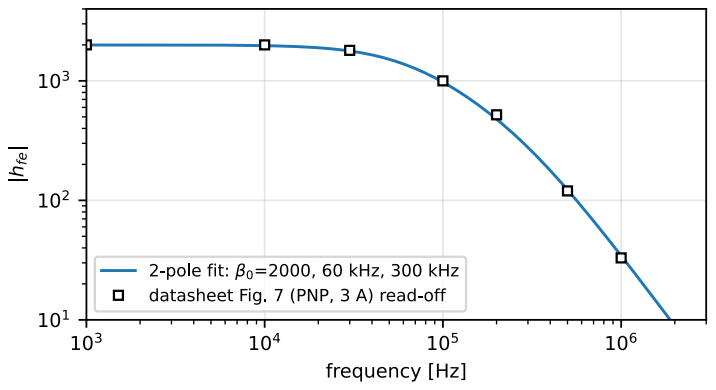
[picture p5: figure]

Figure 2: Two-pole fit of the TIP125 small-signal current gain vs. datasheet Fig. 7 read-off points (PNP, IC = 3 A, VCE = 4 V).

Diodes D1/D2 (bias steering into the driver base) appear only as the divider R3/(R3 + rd

) ≈ 0.97 with rd ≈ 26 Ω.

## 3 Voltage loop (sheet V_loop, p. 2)

### 3.1 Stage 1 — error amplifier / compensator U1

Vset enters the (+) input; the feedback voltage Vfb enters the (−) input through R1

, with the feedback impedance Zf from output to (−):

Zf

(s) = (R2 +

1
sC1

) ∥

1
sC3

, H1

(s) = −

Zf /R1

1 +

1+Zf/R1
A(s)

This is a type-II compensator: an integrator 1/(sR1

(C1 + C3

)), a zero at fz = 1/(2πR2C1

) and a high-frequency pole at fp = (C1 + C3

)/(2πR2C1C3

). With the optimized values R1 = 10 k, R2 = 18 k, C1 =

### 47 n, C3 = 22 p:

fz ≈ 188 Hz, mid-band gain R2 R1

= 1.8 (5.1 dB), fp ≈ 400 kHz.

The finite GBW adds an effective pole near GBW/(1 + R2/R1

) ≈ 2 MHz — a minor extra lag, but included exactly.

### 3.2 Stage 2 — driver and pass transistor (Q1, R3, R4, D1, Q2)

U1′s output drives Q1 (common emitter, degeneration R4
) through D1; Q1′s collector current is the base current of the TIP125, giving a transconductance

H2

(s) =

ic2
Ve

=

R3
R3 + r ⏟d

≈0.97

⋅

1
R4 + r ⏟e1

gm1

⋅ β2

(s) [A/V], Gm =

0.97 ⋅ β0
150 Ω

= 13 A/V (at β0 = 2000).

### 3.3 Stage 3 — output network (R5, C2, load R6)

Q2′s collector acts as a current source into the output capacitor branch and the load:

H3

(s) = Zout(s) = (R5 +

1
sC2

) ∥ [Rload ∥ (ResrL +

1
sCload )].

The load “R6” is whatever the user connects, so Zout — and with it the whole loop — changes with the load: a resistive load leaves the 1/(ωC2

) slope up to the ESR zero, while a large load capacitor drags the crossover down by decades. This is the defining difficulty of the voltage loop.

### 3.4 Stage 4 — sense amplifier U2

A resistive difference amplifier (plus the op-amp’s GBW pole at GBW/(1 + R9/R11

) ≈ 5.3 MHz):

H4 = (1 +

R9
R11

)

R7
R7 + R10

⋅

1
1 + s/ωU2

=

1
15

⋅

1
1 + s/ωU2

,

so the loop regulates Vout = 15 Vset.

### 3.5 Loop gain and compensator design

Figure 3 shows the assembled loop at the nominal load (100 Ω ∥ 1 µF): the integrator crosses the flat mid-band on a clean single slope, the zero at 188 Hz has long since returned the compensator phase, and the crossover lands at fc ≈ 22 kHz with PM ≈ 76°.

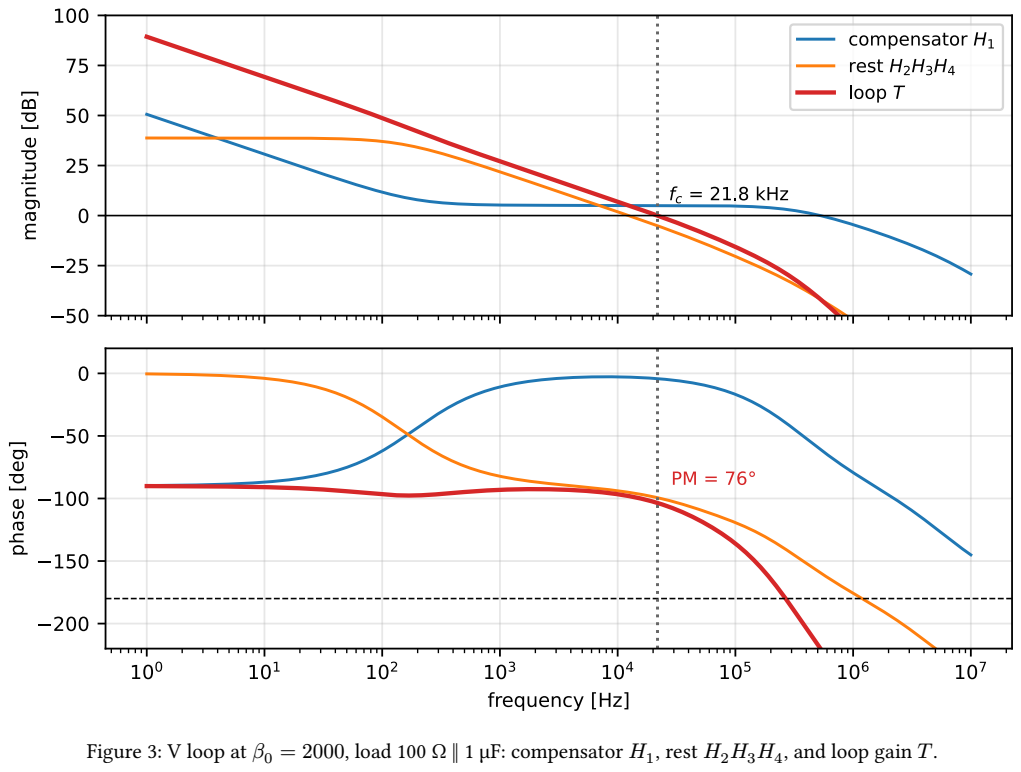
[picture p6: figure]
, rest H2H3H4; , and loop gain T .

Figure 3: V loop at β0 = 2000, load 100 Ω ∥ 1 µF: compensator H1

The values were found by a grid search over E12 components with the corner requirements PM ≥ 45° (≥ 35° for the extreme 1000 µF case), GM ≥ 10 dB and Spk ≤ 1.7 over all corners (β spread × ESR × load set), maximising the worst-case crossover. Two rules of thumb summarise why the result looks the way it does:

1. The zero must sit below the biggest-cap crossover. A large load capacitor drags fc

down; if fc
falls below
fz

the loop reverts to integrator-on-top-of-cap-pole (−180° slope) and the margin collapses. fz = 188 Hz keeps even the β = 500 + 1000 µF corner (fc ≈ 116 Hz) inside the zero’s phase lead.
2. The mid-band gain sets the light-load crossover. R2/R1 = 1.8 keeps the crossover at β0 = 4000 (fc ≈ 45 kHz) clear of the β poles even when the design is denied the help of C2′s ESR zero (ESR corner 50 mΩ).

### 3.6 Robustness across loads and corners

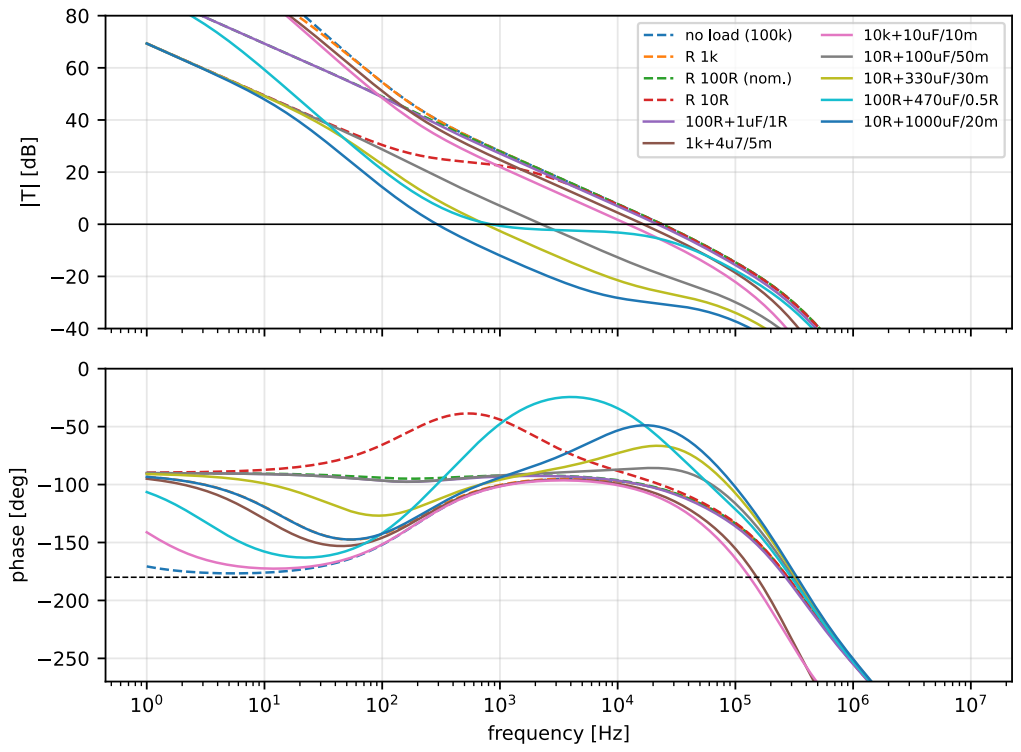
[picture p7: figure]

Figure 4: V-loop gain across 11 load types at β0 = 2000 (dashed: purely resistive). Big capacitors move the crossover down by up to two decades — the compensator must be stable along the whole trajectory.

load case | fc [Hz] | PM [°] | GM [dB] | Spk | worst PM [°] | floor PM [°] | floor Spk
no load (100 k) | 23 930 | 75.6 | 28.1 | 1.15 | 47.8 | 37.0 | 1.99
1 kΩ | 23 926 | 75.7 | 28.1 | 1.15 | 47.8 | 37.0 | 1.99
100 Ω (nominal) | 23 885 | 76.1 | 28.1 | 1.15 | 48.0 | 37.5 | 1.97
10 Ω (heavy) | 23 440 | 79.7 | 28.3 | 1.14 | 50.1 | 42.2 | 1.83
100 Ω + 1 µF/1 Ω | 21 801 | 76.4 | 28.9 | 1.15 | 50.9 | 40.2 | 1.87
1 k + 4.7 µF/5 mΩ | 16 534 | 75.8 | 24.3 | 1.17 | 55.7 | 46.1 | 1.69
10 k + 10 µF/10 mΩ | 12 240 | 77.6 | 26.3 | 1.15 | 62.4 | 53.6 | 1.51
10 Ω + 100 µF/50 mΩ | 2 252 | 89.7 | 44.2 | 1.01 | 86.1 | 84.5 | 1.05
10 Ω + 330 µF/30 mΩ | 749 | 81.1 | 48.7 | 1.01 | 62.7 | 62.7 | 1.03
100 Ω + 470 µF/0.5 Ω | 838 | 126.1 | 32.2 | 1.07 | 61.0 | 61.0 | 1.26
10 Ω + 1000 µF/20 mΩ | 292 | 61.9 | 52.2 | 1.01 | 40.0 | 40.0 | 1.48

Table 1: V loop per load: left half at the typical corner (β0 = 2000, fβ = 60/300 kHz, ESR 0.2 Ω). worst PM = worst case over the β/ ESR corners with datasheet β poles (valid if the 12 mA sink holds the Fig.-7 poles); floor PM / floor Spk = additionally including the ÷3 low-bias pole corner — the guaranteed bound at ≥ 12 mA bias. The global worst with datasheet poles is the 1000 µF case (40.0°, β = 4000) — a load property, not a bias property.

β corner | fc range [Hz] | worst PM [°] | min GM [dB] | max Spk
β = 500 | 116 … 6 188 | 40.0 | 35.0 | 1.48
β = 1000 (min spec) | 178 … 12 279 | 49.5 | 28.9 | 1.21
β = 2000 (typical) | 292 … 23 930 | 61.9 | 22.9 | 1.33
β = 4000 (typ. peak) | 522 … 44 766 | 47.8 | 16.9 | 1.64
β = 1000, low-bias | 178 … 10 920 | 49.1 | 19.6 | 1.49
β = 2000, low-bias | 291 … 18 403 | 37.0 | 13.6 | 1.99

Table 2: V loop worst case per β corner, over all 11 loads and both ESR values. The binding corners are β = 4000 with low-ESR C2 (fast side) and the doubly derated low-bias case (slow side); both remain stable with sensible margin. The two low-bias rows are the floor guaranteed by the 12 mA minimum-load sink — they no longer bind if 12 mA holds the datasheet β poles.

### 3.7 Setpoint step and prefilter

The closed-loop response from the setpoint is

Vout

Vset

=

Gm(s)Zout (1 + Zf /R1

)
1 + T

,

whose numerator carries the noise-gain term (1 + Zf /R1

) — the compensator zero appears in the reference path with a zero at

fz,ref =

1
2π(R1 + R2

)C1

≈ 121 Hz.

A setpoint edge therefore feeds forward and overshoots by ≈ 54 % — not ringing (the loop is critically damped); it disappears if the setpoint never contains energy above that zero. The clean fix is an RC low-pass in front of the (+) input with its pole matched to the zero: τ = (R1 + R2

)C1 ≈ 1.32 ms, e.g. 27 k + 47 n. The zero then cancels the filter pole (Figure 5). Note that R1C1
alone (470 µs) is not the match — it leaves about 13 %.

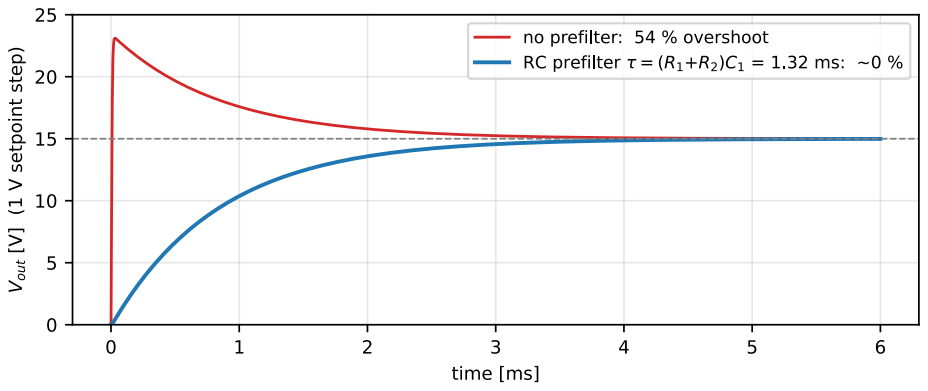
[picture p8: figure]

Figure 5: Closed-loop 1 V setpoint step (β0 = 2000, nominal load) with and without the matched RC prefilter.

## 4 Current loop (sheet I_loop, p. 3)

### 4.1 Stages 1, 2 and 4

The error amplifier U3 and the driver Q3/Q4 are identical in topology to the voltage loop (R8 = 10 k input resistor, R15 = 150 Ω degeneration, same TIP125 model). The optimized compensator is a pure integrator — R12

and C5
stay unpopulated:

H1

(s) = −

1/(sR8C4

)
1 + (1 + 1/(sR8C4

))/A(s)

, C4 = 27 n → unity gain at

1
2πR8C4

≈ 589 Hz.

The sense amplifier U4 is non-inverting with gain 1 + R16/R17 = 12; its noise gain of 12 pulls the op-amp pole down to GBW/12 ≈ 475 kHz — low enough to matter alongside the β poles:

H4

(s) =

12
1 + s/(2π ⋅ 475 kHz)

, Vfb = 12 ⋅ R21

⋅ I = 2.4 V/A (I ≈ 417 mA per volt of Vset).

### 4.2 Stage 3 — the flat, load-independent plant

Here the schematic differs decisively from the voltage loop: the output-capacitor branch (R19 + C6 ) and the load
R20

both return to the top of the shunt R21
, not to ground. Every milliampere that Q4 sources must therefore pass through the shunt, and Kirchhoff’s current law gives, exactly and at every frequency,

iR21

= iC6

+ iload = ic4 ⇒ H3

(s) =

Vsh

ic4

= R21 = 0.2 Ω.

The load impedance, C6

and R19 drop out of the loop gain completely — they only set the voltage at the output node, which the regulated variable never sees. The loop is identical for a short, a resistor, or 1000 µF. Including Q4′s finite output resistance (ro ≈ 2 k pessimistic) and output capacitance (Cob ≤ 300 pF) merely adds a static gain error up to ≈ 5 % at light load (a current-divider effect, calibration territory) and no dynamics below the MHz range.

### 4.3 Loop gain — why a pure integrator

With a flat plant, the “rest” of the loop is a constant 0.97β0R21

⋅ 12/R15 ≈ 31 (30 dB at β0 = 2000) with the β/U4 poles hanging off the top (Figure 6). A single integrator crosses it on a clean −20 dB/dec slope: crossover

fc ≈

0.97 β0 R21

(1 + R16/R17

)
2πR8C4R15

= 17.6 kHz at β0 = 2000.

A voltage-loop-style zero (R12 > 0) would be actively harmful here: it flattens the compensator above fz
, and with
the 8:1 β-gain spread the crossover would slide across that flat region straight into the β poles. Keep R12 = 0. C4 = 27 n is the speed/margin knee: 22 n is ≈ 20 % faster but sits at the acceptance edge (low-bias Spk ≈ 2), 47 n is the conservative fallback (PM ≥ 65°).

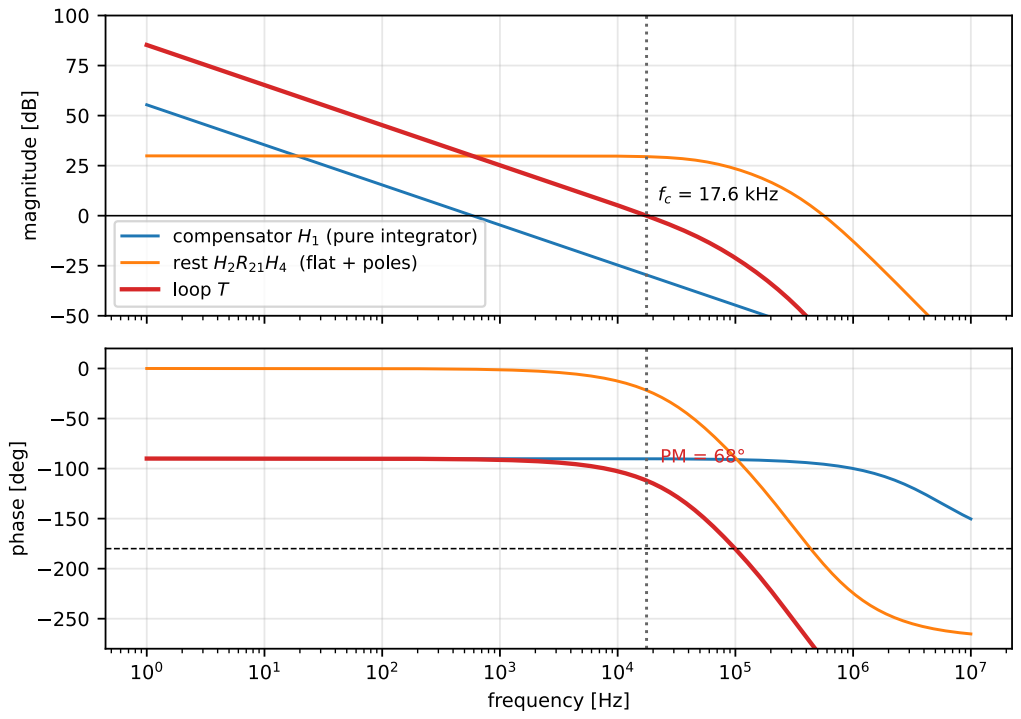
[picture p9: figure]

Figure 6: I loop at β0 = 2000: integrator, flat rest, and loop gain. The phase budget at crossover is −90° (integrator) minus the β-pole lag.

### 4.4 Corner sweep

β corner | fc [Hz] | PM [°] | GM [dB] | Spk
β = 500 | 4 582 | 84.2 | 33.1 | 1.08
β = 1000 (min spec) | 9 082 | 78.5 | 27.1 | 1.15
β = 2000 (typical) | 17 597 | 68.0 | 21.0 | 1.30
β = 4000 (typ. peak) | 32 148 | 51.5 | 15.0 | 1.60
β = 1000, low-bias | 8 437 | 61.2 | 20.3 | 1.39
β = 2000, low-bias | 14 662 | 43.5 | 14.3 | 1.78

Table 3: I loop margins per β corner. The numbers are identical for every load — the load does not appear in T (s) (Section 4.2). Worst case with datasheet β poles: 51.5° (β = 4000); the low-bias rows are the 12 mA-sink-guaranteed floor (43.5° worst). The sink bypasses the shunt, so it adds no offset to the sensed current — CC regulates the true load current and setpoints below 12 mA remain

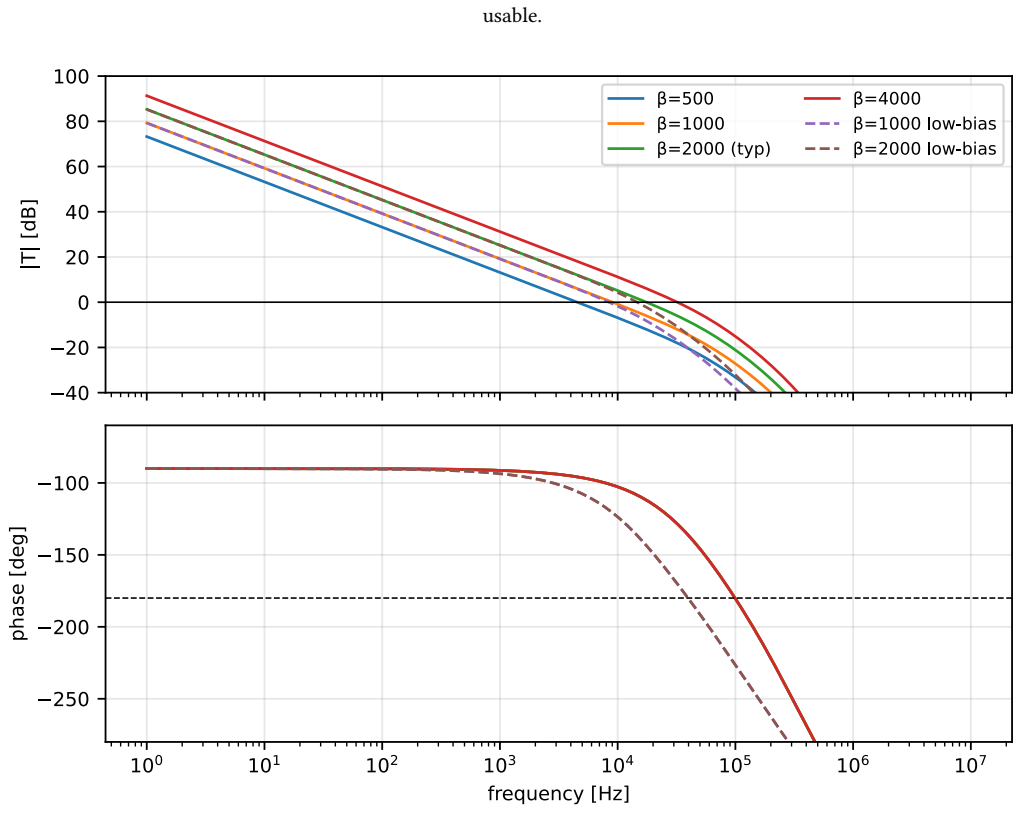
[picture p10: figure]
usable.

Figure 7: I-loop gain across the TIP125 β corners (dashed: low-bias derated poles). Only the gain scales; the pole structure — and therefore the phase curve — barely moves.

### 4.5 Setpoint step — the feed-forward spike

Because the plant has no inertia (a flat 0.2 Ω, no output pole in the current path), a Vset edge feeds through the noise-gain term (1 + Zf /R8

) → 1 directly to the driver and commands ΔI ≈ GmΔVset ≈ 13 A/V for the few microseconds (1/2πfc ≈ 9 µs) the integrator needs to take over — the small-signal model shows a spike of more than 2000 % (Figure 8, left). Hardware clips it (op-amp swing and 2.8 V/µs slew, Q3′s emitter resistor), but the lesson stands: the current setpoint must never step hard. The matched RC prefilter (pole on the reference zero at 1/2πR8C4 = 589 Hz, i.e. τ = R8C4 = 270 µs, 10 k + 27 n) removes the spike while keeping the setpoint response fast, because the compensator zero cancels the filter pole (Figure 8, right).

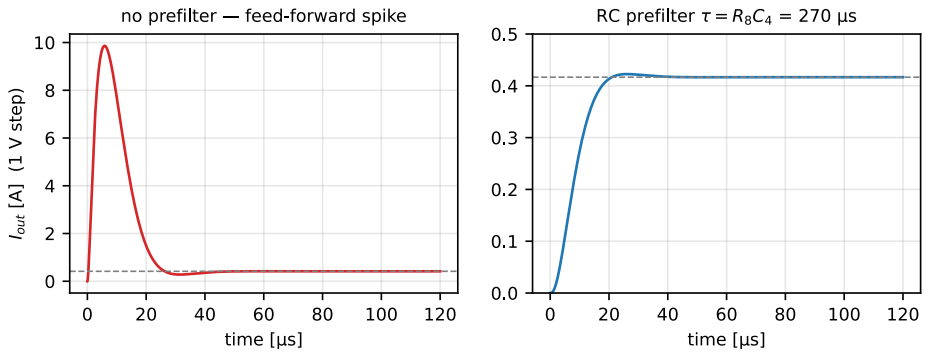
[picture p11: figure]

Figure 8: I loop, 1 V setpoint step at β0 = 2000. Left: unfiltered — the feed-forward spike reaches amperes for a few µs (model; hardware clips it). Right: with the matched 270 µs prefilter — ≈ 1.4 % residual, settled in ≈ 20 µs.

## 5 Setpoint prefilters — general rule

Both overshoots have the same root cause: the compensator’s feedback impedance appears in the reference path as (1 + Zf /Rin), whose zero lets a setpoint edge feed forward. The matched RC prefilter puts its pole exactly on that zero:

τfilt = (Rin + Rzero) ⋅ Cint

loop | reference zero | matched τ | suggested RC | result (1 V step)
V loop | 1/2π(R1 + R2 )C1 ≈ 121 Hz | 1.32 ms | 27 k + 47 n (or 10 k + 120 n) | 54 % → ≈ 0 %
I loop | 1/2πR8C4 ≈ 589 Hz | 270 µs | 10 k + 27 n | 2267 % → 1.4 %, settle ≈ 20 µs

Table 4: Matched setpoint prefilters. The filter is a series R + C-to-ground directly at the error amp’s (+) input (high impedance). A firmware DAC ramp of ≈ 1 ms is the part-free alternative. Note the values track the compensator: change C1

/C4
and the filter caps
follow.

Because the reference zero contains only compensator parts, the cancellation is independent of the TIP125 β and of the load.

## 6 Summary

part | schematic first guess | final value | role
V: R1 | 10 k | 10 k (keep) | input / gain reference
V: R2 | 10 k | 18 k | zero at 188 Hz, mid-band gain 1.8
V: C1 | 1 n | 47 n | integrator; zero with R2
V: C3 | — | 22 p | HF pole ≈ 400 kHz
I: R8 | 10 k | 10 k (keep) | input / gain reference
I: C4 | — | 27 n | pure integrator, unity at 589 Hz
I: R12 , C5 | — | DNP | a zero would be harmful (flat plant)
V prefilter | — | 27 k + 47 n | kills 54 % setpoint overshoot
I prefilter | — | 10 k + 27 n | kills the feed-forward current spike

Table 5: Final component values (all E12).

Resulting worst-case margins (with the ≈ 12 mA minimum-load sink keeping the pass device biased) — V loop: PM ≥ 40° with datasheet β poles (the binding case is the extreme 10 Ω + 1000 µF load at β = 4000; every normal load stays ≥ 47.8°), GM ≥ 16.9 dB; the ÷3-derated low-bias floor bottoms at 37°. Typical-β margins 62–126°. I loop: PM ≥ 51.5°, GM ≥ 15 dB over the full β spread (low-bias floor 43.5°), for any load. Before the sink, the low-bias corner was an open-ended assumption — the pass device idled at the 1 mA divider current and nothing bounded the fβ
collapse; now it is a guaranteed floor.

Not covered by these AC models, to be verified on hardware: the CV↔CC handover through the D1/D2 diode-OR (the losing loop’s integrator saturates and must slew back — an anti-windup clamp shortens the transition), how far the TIP125 β poles actually derate at the 12 mA minimum bias (bounded by the LB corner, but Fig. 7 is specified at 3 A), and thermal drift of the TIP125 parameters.

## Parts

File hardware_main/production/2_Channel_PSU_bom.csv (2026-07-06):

Designator | Footprint | Quantity | Value | LCSC Part #
A401 | Waveshare_PR2350_tiny | 1 | Waveshare RP2350-Tiny
C1001, C1002, C101, C102, C105, C107, C120, C135, C136, C140, C141, C143, C145, C201, C309, C405, C501, C502, C509, C511, C512, C513, C601, C603 | 1206 | 24 | 10u
C1003, C1015, C103, C104, C106, C108, C109, C115, C117, C118, C1205, C126, C128, C1301, C132, C144, C147, C301, C302, C307, C310, C402, C503, C505, C703, C704, C801, C802, C803, C805, C806, C903 | 0603 | 32 | 100n
C1004, C1203, C904 | 0603 | 3 | 100p
C1005, C1007, C124, C131, C905, C906, C907 | 0805 | 7 | 22u
C1006, C1009, C1010, C1011, C127, C1303, C139, C142, C146, C202, C404, C808, C901, C902 | 0805 | 14 | 10u
C1008, C133, L201, L401 | 0805 | 4 | 1u
C1012, C1013, C1201, C1202 | 0603 | 4 | 2,2u
C1014, C1204 | 0603 | 2 | 22p
C110, C122, C123, C203, C504, C507, C804 | 0603 | 7 | 1u
C111, C303 | 0603 | 2 | 47n
C112, C1302, C304, C807 | 0603 | 4 | 27n
C113, C114, C701, C702 | 0603 | 4 | 4,7u
C119, C137, C1401, C506, C510, C908, R110, R122, R503, R505 | 0603 | 10 | opt
C121, C130, C134, C305, C306, C308 | 0603 | 6 | 10p
C125, C602 | 1210 | 2 | CHV1210N1K0103KXT
C129, C508 | 0603 | 2 | 1n
C138, C604 | CP_Elec_8x10.5 | 2 | 100u
D1001, D105, D903 | 0603 | 3 | green LED 3V3
D1002, D106 | 0603 | 2 | green LED -5V
D1003, D1004, D1006, D1007, D1008, D1201, D1202, D1204, D1205, D1206 | D_SOD-323 | 10 | 1N4148WS
D1005, D1203 | D_SOD-323 | 2 | MM3Z4V7T1G
D101, D601 | D_SMB | 2 | SMBJ40A
D103, D107, D801, D802 | 0603 | 4 | red LED 3V3
D104, D602 | 0603 | 2 | green LED 40V
D1401, D904 | 0603 | 2 | green LED PG
D201, D401 | D_SMB | 2 | SMBJ36A
D901 | D_SMB | 1 | SMBJ12A
D902 | 0603 | 1 | green LED 12V
F101, F601, F901 | 1206 | 3 | 3,5A
F102, F301 | 1206 | 2 | 3A
FL101, FL601 | L_CommonModeChoke_Murata_DLW5BTMxxxSQ2x_5x5mm | 2 | DLW5BTM102TQ2L
J101, J601, J901 | PhoenixContact_MCV_1,5_2-G-3.81_1x02_P3.81mm_Vertical | 3 | Power Input
J102, J801 | JST_SH_BM03B-SRSS-TB_1x03-1MP_P1.00mm_Vertical | 2 | Conn_01x03_Pin
J103, J802 | PinHeader_2x02_P2.54mm_Horizontal | 2 | Conn_02x02_Odd_Even
J201, J402 | Banana_Cliff_FCR7350R_S16N-PC_Horizontal | 2 | Banana_Red
J202, J403 | Banana_Cliff_FCR7350B_S16N-PC_Horizontal | 2 | Banana_Black
J203 | PinHeader_2x04_P2.54mm_Horizontal | 1 | Conn_02x04_Odd_Even
J204 | IDC-Header_2x05_P2.54mm_Vertical | 1 | Conn_02x05_Odd_Even
J205 | PinHeader_1x04_P2.54mm_Vertical | 1 | Conn_01x04_Pin
L1001, L101 | L_TDK_VLS6045EX_VLS6045AF | 2 | 33u VLS6045EX-330M
L102, L501 | L_Wuerth_MAPI-4030 | 2 | 10u 74438357100
L901 | 1210 | 1 | 6,8u LBC3225T6R8MR
M401 | FanPinHeader_1x04_P2.54mm_Vertical | 1 | Fan_4pin
Q101, Q501 | SOT-23-3 | 2 | MMBT3906
Q102, Q107, Q301, Q304 | SOT-223 | 4 | BCP56
Q103, Q302 | SOT-23-3 | 2 | BSS138
Q104, Q303 | TO-220-3_Horizontal_TabUp | 2 | TIP125
Q105, Q106, Q1401, Q801, Q802, Q901 | SOT-23 | 6 | BSS138
R1001, R114 | 0603 | 2 | 75k
R1002, R115 | 0603 | 2 | 16,2k
R1003, R124, R136, R140, R1401, R803, R806, R905 | 0603 | 8 | 2,4k
R1004, R139, R901, R904 | 0603 | 4 | ###
R101, R102, R103, R109, R113, R120, R1302, R1402, R201, R202, R203, R204, R205, R301, R302, R310, R501, R801, R802, R808, R906 | 0603 | 21 | 10k
R104, R105, R118, R125, R135, R137, R308, R404, R506, R701, R702, R804, R805 | 0603 | 13 | 1k
R106, R303 | 0603 | 2 | 18k
R107, R121, R304, R311 | 0603 | 4 | 0
R108, R502 | 0603 | 2 | 60,4k
R112, R305 | 0603 | 2 | 1,2k
R116, R119, R306, R309 | 0603 | 4 | 2,2k 0,1%
R117, R307 | 0603 | 2 | 3,3k
R123, R312 | 0603 | 2 | 220
R126, R507 | 0603 | 2 | 4,99k
R127, R128, R313, R314 | 0603 | 4 | 33k 0,1%
R129, R315 | 1206 | 2 | 150
R130, R508, R903 | 0603 | 3 | 62k
R1301, R807 | 0603 | 2 | 12k
R131, R316 | 0603 | 2 | 11k 0,1%
R132, R317 | 0603 | 2 | 1k 0,1%
R133, R509 | 0603 | 2 | 100k
R134, R601 | 0603 | 2 | 38k
R138, R318 | 2512 | 2 | 100m
R141, R319 | 1206 | 2 | 200m
R142, R320 | 0603 | 2 | 47
R902 | 0603 | 1 | 196k
TH101, TH801 | 0603 | 2 | NCU18XH103F60RB
TH201 | Flex NTC | 1 | Thermistor_NTC
TP101, TP301 | TestPoint_Pad_D1.0mm | 2 | Vsense
TP102, TP302 | TestPoint_Pad_D1.0mm | 2 | CV_loop
TP103, TP303 | TestPoint_Pad_D1.0mm | 2 | CC_loop
TP104, TP304 | TestPoint_Pad_D1.0mm | 2 | CC/CV
TP105, TP305 | TestPoint_Pad_D1.0mm | 2 | Isense
TP106, TP107, TP110, TP1401, TP1506, TP501, TP502, TP503, TP608, TP901 | TestPoint_Pad_D1.0mm | 10 | TestPoint_Alt
TP108, TP112, TP1503, TP1504, TP1505, TP201, TP202, TP203, TP401, TP402, TP403, TP505, TP601, TP605, TP606, TP607 | SMD Test Point PCWCTE | 16 | TestPoint
TP1501, TP1502, TP1507, TP306, TP307, TP308, TP602, TP603, TP604 | TestPoint_Keystone_5005-5009_Compact | 9 | TestPoint_Alt
U1002, U109 | SOT-89-3 | 2 | AP7383
U1003, U110 | SOT-23-6 | 2 | LM2776
U1004, U111 | SC-74A-5_1.55x2.9mm_P0.95mm | 2 | XC6901D121MR-G
U101, U301 | TSSOP-14_4.4x5mm_P0.65mm | 2 | TLV4387PWR
U102, U801 | SOIC-8_3.9x4.9mm_P1.27mm | 2 | ISO6721RFBD
U104, U501 | QFN-28-1EP_3x6mm_P0.5mm_EP1.7x4.75mm_ThermalVias | 2 | LT8612
U105, U302 | SOT-353_SC-70-5 | 2 | LMV331
U106, U802 | SOIC-14_3.9x8.7mm_P1.27mm | 2 | ATtiny1614-SS
U107, U701 | TSSOP-10_3x3mm_P0.5mm | 2 | ADS1118IDGS
U108, U702 | MSOP-10_3x3mm_P0.5mm | 2 | MCP48FVB22
U1501, U601 | SOT-23-6 | 2 | LMR51606
U901 | TSOT-23-6 | 1 | AP63200WU

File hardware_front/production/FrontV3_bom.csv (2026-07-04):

Designator | Footprint | Quantity | Value | LCSC Part #
BZ401 | Buzzer_12x9.5RM7.6 | 1 | Buzzer
C2, C6 | 0805 | 2 | 10u
C3, C5, C7 | 0603 | 3 | C
C4 | 0603 | 1 | 10n
D1, D2, D3, D4 | LED_D3.0mm_FlatTop | 4 | LED_green
D5, D6 | LED_D3.0mm_FlatTop | 2 | LED_red
J2 | PinSocket_2x08_P2.54mm_Vertical | 1 | OLED
J3, J4 | PinSocket_2x02_P2.54mm_Vertical | 2 | Conn_02x02_Odd_Even
J5 | PinSocket_2x04_P2.54mm_Vertical | 1 | Conn_02x04_Odd_Even
J6 | PinSocket_1x04_P2.54mm_Vertical | 1 | Conn_01x04
Q401 | SOT-23-3 | 1 | BSS138
R10, R12, R13, R14, R201, R8 | 0603 | 6 | 10k
R15, R16, R17, R18, R19, R20 | 0603 | 6 | xx
R403 | 0603 | 1 | 1k
R7, R9 | 0603 | 2 | R
SW1, SW2, SW3, SW4, SW5, SW8 | SW_PUSH_6mm_H13mm | 6 | SW_Push 18mm
SW7 | RotaryEncoder_Alps_EC11E-Switch_Vertical_H20mm | 1 | RotaryEncoder_Switch_MP
TP7, TP8 | TestPoint_Pad_D1.5mm | 2 | TestPoint
U3 | SSOP-20_5.3x7.2mm_P0.65mm | 1 | MCP23008T-E/SS

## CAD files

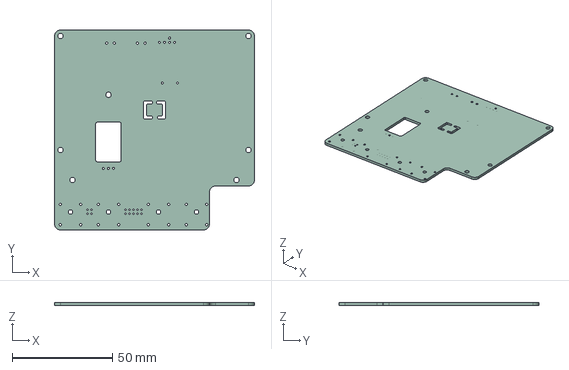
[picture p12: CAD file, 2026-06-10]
hardware_main/only_PCB.step
100.0 x 100.0 x 1.51 mm

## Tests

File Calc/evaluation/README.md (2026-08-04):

# Evaluation — bench measurements against a reference instrument

Scripts that measure the *built* power supply and compare it against a
calibrated reference. This is the empirical counterpart to the paper analyses in
[Calc/DAC_ADC/](../DAC_ADC/) and [Calc/Stability/](../Stability/).

| Script | What it does |
|---|---|
| [psu_accuracy.py](psu_accuracy.py) | Ramps one channel 0 → 36 V (or 0 → 2 A) and plots setpoint- and readback-error against a Siglent SDM3065X |
| [cal_probe.py](cal_probe.py) | Recovers the `IMEAS` gain/offset actually stored in the channel and compares it with the fit it should have produced — stands in for the missing `CAL:DATA?` |
| [net_stress.py](net_stress.py) | SCPI-over-Ethernet stress and liveness harness (see the brain's network-hang notes) |

Results (CSV + report + PNGs) are written to `results/`, one timestamped set per
run.

---

## psu_accuracy.py

### What it measures

At each of the 73 ramp steps the script collects three numbers:

| Symbol | Source | Meaning |
|---|---|---|
| `v_set` | what we wrote with `VOLT <x>` | the request |
| `v_psu` | `MEAS:VOLT?` | what the PSU *thinks* it is doing |
| `v_dmm` | SDM3065X `READ?` | ground truth |

and reports the two deviations:

- **setpoint error** = `v_set − v_dmm` — exercises the **DAC → Vset** path
  (MCP48FVB22 band gap, the 12-bit code grid, the post-reg loop). This is what
  `CAL:POIN VSET,…` corrects.
- **readback error** = `v_psu − v_dmm` — exercises the **Vsense → ADC** path
  (difference amp, ADS1118). This is what `CAL:POIN VMEAS,…` corrects.

Both paths are independent, which is why they are plotted as two separate
series rather than being folded into one "accuracy" number.

### Two panels

1. **Absolute deviation (mV)** — the headline. Flat-and-nonzero means offset,
   sloped means gain error.
2. **Relative deviation (% of reading)** — the spec-sheet view. Points below
   `--rel-floor` (default 1 V) are dropped, because dividing a fixed offset by
   a near-zero reading produces a meaningless spike.

The text report additionally prints gain error, offset, worst/rms error, a
`worst non-linearity` row, and a ready-to-paste `CAL:POIN` sequence built from
the two points nearest 10 % and 90 % of full scale.

**`worst non-linearity`** is the residual left after a least-squares gain/offset
line is removed — the part a 2-point calibration **cannot** fix, so it is the
real accuracy floor of the hardware. Compare it against the quantisation floor
printed directly beneath it, and against the ±0.05 % predicted in
[DAC_ADC_Accuracy_Analysis.md](../DAC_ADC/DAC_ADC_Accuracy_Analysis.md); 12-bit
DAC quantisation alone is ~8.6 mV, so a sawtooth of that amplitude on the
setpoint trace is expected, not a defect. (This used to be a third plot panel;
it is analysis of the calibration scheme rather than of the instrument, so it now
lives only in the report.)

### Excluded endpoints

The report and plots leave out the two ramp endpoints the channel physically
cannot reach, because each one dominates every statistic it appears in:

- the **0 V / 0 A setpoint**, which sits on the output floor (CH1 measures
  31.6 mV for a 0 V request), and
- the **clipped top** of a current ramp, above the ISET DAC ceiling — one such
  point took CH2's worst setpoint error from ~1 mA to 49 mA.

Clipping is only ever detected as a contiguous tail exceeding `--clip-tol`
(default 5 setpoint LSB), so a genuinely poor calibration is never silently
discarded as "clipping". Both endpoints stay in the CSV, which is the raw
measurement record. `--keep-endpoints` reports every point.

### Wiring

```
PSU CH<n> OUT+ ────────────────► SDM3065X  HI (DC V)
PSU CH<n> OUT− ────────────────► SDM3065X  LO
```

Run it **open-circuit** apart from the DMM. The SDM3065X draws >10 GΩ on its
2 V/20 V ranges and 10 MΩ on the 200 V range (≈3.6 µA at 36 V), so the current
reading should stay at zero; `--abort-current` (default 20 mA) stops the ramp if
it does not, which catches a shorted or loaded output.

> **Settling vs step size.** 500 mV steps settle well inside the 0.6 s default.
> A large step does not: measured on this unit, 0 V → 15 V in one jump is still
> slewing 0.6 s later (the DMM read 1.87 V low). If you raise `--vstep` much
> above ~1 V, raise `--settle` with it.

> With `--dmm-range AUTO` the DMM switches 2 V → 20 V → 200 V during the ramp,
> and its input impedance changes with it. That is the most accurate choice and
> is harmless here, but if you see a step in the error curve right at 20 V, pin
> the range with `--dmm-range 200` and re-run to confirm it is the DMM and not
> the PSU.

### Prerequisites

- Python 3 with `numpy` and `matplotlib` (already present on this machine).
  **No pyvisa/VISA runtime needed** — both instruments are driven over raw SCPI
  on TCP port 5025.
- PSU firmware ≥ 0.2.0 with the SCPI server (see
  [firmware/SCPI/commands.md](../../firmware/SCPI/commands.md)); the PSU must
  have an IP (front panel → *Settings → Network*).
- SDM3065X on the same subnet, LAN enabled.

### Usage

```powershell
# full 0..36 V ramp on CH1
py psu_accuracy.py --psu 192.168.1.50 --dmm 192.168.1.51

# CH2, coarser and faster (per-point markers appear at <=40 points)
py psu_accuracy.py --psu 192.168.1.50 --dmm 192.168.1.51 `
    --channel 2 --vstep 2.0 --nplc 1 --dmm-samples 1 --settle 0.3

# verify the post-calibration residual only over the useful span
py psu_accuracy.py --psu ... --dmm ... --vmin 1 --vmax 36 --tag after_cal

# no hardware: modelled instruments, exercises the whole pipeline
py psu_accuracy.py --simulate

# re-draw plots/report from a stored run
py psu_accuracy.py --replot results/ramp_i_ch1_20260804_224335_ch1_imeas_fix.csv
```

Key options (`--help` lists them all):

| Option | Default | Notes |
|---|---|---|
| `--vmin / --vmax / --vstep` | 0 / 36 / 0.5 V | the setpoint grid is 10 mV, so keep steps a multiple of that |
| `--ilim` | 0.050 A | current limit held during the ramp |
| `--settle` | 0.6 s | dwell after each step before measuring |
| `--dmm-samples` / `--psu-samples` | 3 / 3 | readings averaged per step |
| `--nplc` | 10 | DMM integration time; 10 NPLC ≈ 0.2 s/reading at 50 Hz |
| `--dmm-range` | AUTO | or `2`, `20`, `200` |
| `--abort-current` | 0.020 A | safety abort |
| `--max-deviation` | 3.0 V | aborts on a grossly wrong reading (wrong leads/range) |
| `--theme` | both | light and dark PNGs |

A full 73-point run at the defaults takes roughly 1½–2 minutes.

### Safety

The output is set to 0 V and switched **off** in a `finally` block, so Ctrl-C,
a timeout or an instrument error all leave the supply in a safe state. The PSU
error queue is drained before and after the ramp and anything it reports is
printed.

### Calibration (`--calibrate`) — and why it probably won't help

```powershell
py psu_accuracy.py --psu ... --dmm ... --channel 1 --calibrate --verify
```

Drives `--cal-low` (3.5 V) and `--cal-high` (32.5 V), waits `--cal-settle`,
reports the averaged DMM reading with `CAL:POIN`, then commits. `--verify`
re-runs the ramp afterwards, and the residual at each cal point is checked and
reported either way — a 2-point fit must pass through its own two points, so
that residual is the one check the missing `CAL:DATA?` cannot hide.

**`--cal-settle` is the whole ballgame for the measure paths.** The channel
captures `x` from an average of the raw ADC volts taken right after the channel
steps to the point, so any lag left in that average is stored as the point's
`x` and comes straight back as gain/offset error. This is what caused the
measure-path calibration bug — the old 3 s default stored a 2.2 % `IMEAS` gain
error while reporting success. The default is now 12 s, which is comfortable on
firmware carrying the `measure.cpp` alpha = 1/4 + snap fix (the reasoning is in
that file's comment); on older firmware use 20 s or more.

Calibrate a channel that has been running, not one straight from idle: CH2
calibrated cold came out at +0.033 % gain, and re-running it once thermally
soaked gave +0.019 %.

Two properties of the firmware make this safe:

- The fit is **absolute**, not incremental — `x` = the true value, `y` = the raw
  hardware quantity (the DAC code for VSET, raw ADC volts for VMEAS). Calibrating
  an already-calibrated channel converges rather than compounding.
- Each point is captured **live**, from whatever the channel is doing when
  `CAL:POIN` arrives. Values from a stored run cannot be replayed — hence a
  script rather than a paste-in command list.

One thing it is **not**: reversible. `CALibration:DATA?` returns NaN (the
constants can't be read back over the channel link), so the present calibration
cannot be saved first, and `CAL:RESet` restores compile-time defaults rather than
your previous values. Two ways round that: [cal_probe.py](cal_probe.py) recovers
the stored `IMEAS` line from SCPI readbacks alone (good to ~0.02 % on gain), and
a UPDI adapter can read the whole EEPROM out byte-for-byte — see the flash-status
section of the handover for the procedure.

> **Measured outcome on this unit (2026-08-03):** recalibrating VSET+VMEAS on
> both channels changed nothing beyond noise. Both were already at their floor:
> the setpoint residual is DAC INL (a bow between the cal points) plus ±½ LSB
> rounding, and the readback residual is ~1 ADC LSB. **A 2-point linear fit pins
> the endpoints; it cannot remove a bow between them.** Before calibrating,
> check the `worst non-linearity` row — if the residual is a bow rather than a
> tilt or a step, calibration has nothing to grip.

### Interpreting a first, uncalibrated run

Expect a **gain error of a few percent** dominated by the DAC's internal band
gap (±3.3 %) — that is the known consequence of the unconnected `Vref` pin and
is exactly what the 2-point calibration exists to remove. What matters on a
first run is `worst non-linearity`: if the residual is within a few mV, the
hardware is good and calibration will do the rest. A residual that grows with
voltage, or a kink, points at something real (post-reg loop, sense-amp resistor
matching, thermal drift) rather than at a missing calibration.

Re-confirmed on 2026-08-04: CH1's voltage paths were measured again a day later
and had not moved (VSET 8.78 mV rms / −0.0005 % gain, VMEAS 0.74 mV rms /
+0.0025 % gain, both within ~0.1 mV of the previous run). Still nothing for a
calibration to correct, so none was run.

### Current ramps

`--quantity current` ramps 0 → 2 A instead, with the DMM's own current input as
the load and `--compliance` setting the voltage limit. Pin the DMM range
(`--dmm-range 2`): on AUTO the SDM3065X reads ~1.2 % high around 250 mA, having
overranged its 200 mA range before stepping up. Unlike the voltage paths, the
current paths *do* respond to calibration — see the README accuracy section.

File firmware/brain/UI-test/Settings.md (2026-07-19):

# Settings — Submenu Structure

## Channel 1 Settings

| Item | Description |
| --- | --- |
| Temp | Measured temperature |
| Volt | Measured voltage |
| Curr | Measured current |
| OTP | Set OTP (0–100 °C); reads the OTP from the channel and updates it if changed|
| DAC state | OK / not OK |
| ADC state | OK / not OK |
| Communication | OK / not OK (comm of channel with brain) |
| Runtime | Read from channel: the operating time |
| Cal values V  | Read from channel and display them |
| Cal values I  | Read from channel and display them |
| Manual Cal V  | Enter manual cal procedure for voltage (add confirmation so it is not pressed axidantely) |
| Manual Cal I  | Enter manual cal procedure for current (add confirmation so it is not pressed axidantely) |

## Channel 2 Settings

Same as Channel 1.

## Temp and Fan Settings

| Item | Description |
| --- | --- |
| Temp Ch1 | Measured temperature CH1 |
| Temp Ch2 | Measured temperature CH2 |
| Temp heatsink  | Measured temperature brain (heatsink) |
| Temp max | Max of all 3 |
| SYS OTP | OTP setpoint managed by the brain; compared against max temp |
| Fan min speed  | Setpoint of fan minimum speed (%) |
| Fan start temp | Setpoint of fan start temperature (0–100 °C) |
| Fan max temp | Setpoint of fan max temperature (0–100 °C) |

## Network

| Item | Description |
| --- | --- |
| Status | Link up / down, current IP (read only, actual values in use) |
| MAC address | e.g. `A8:61:0A:12:34:56` (read only) |
| DHCP | ON / OFF — when ON: IP/Netmask/Gateway below are read only and show the leased values |
| IP address  | e.g. `192.168.1.50` (set with encoder, octet by octet) |
| Netmask | e.g. `/24` (set with encoder as CIDR prefix, shown as `255.255.255.0`) |
| Gateway | e.g. `192.168.1.1` (set with encoder, needed for access from other subnets) |
| Hostname | e.g. `psu-2ch` |
| Apply | Applies the settings above and restarts the network interface |

Edits do nothing until **Apply**, so a half-edited IP config never goes live.

## System

| Item | Description |
| --- | --- |
| firmware version | fw version |
| remember set values on restart| Yes/No |
| Beeper | ON / OFF |
| Brain runtime | Brain runtime|

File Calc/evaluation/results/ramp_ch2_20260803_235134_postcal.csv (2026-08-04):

# timestamp: 2026-08-03T23:54:33
# channel: 2
# psu_idn: PreReg | PSU-2CH-36V2A | SN00001 | 0.2.0
# dmm_idn: Siglent Technologies | SDM3065X | SDM36HCQ7R1239 | 3.02.01.12R1
# vmin_V: 0.0
# vmax_V: 36.0
# vstep_V: 0.5
# ilim_A: 0.05
# settle_s: 0.6
# dmm_range: AUTO
# nplc: 10.0
# dmm_samples: 3
# psu_samples: 3
# simulated: False
index | t_s | v_set | v_dmm | v_dmm_sd | v_psu | i_psu
0 | 3.5952719000633806 | 0.0 | 0.020015591 | 0.0001191745263849631 | 0.019 | 0.0
1 | 7.130347399972379 | 0.5 | 0.4995800803333334 | 0.0002934532132152137 | 0.49899999999999994 | 0.0
2 | 9.264732900075614 | 1.0 | 0.9969945106666667 | 4.32961081084136e-05 | 0.996 | 0.0
3 | 11.366423100000247 | 1.5 | 1.4959018433333335 | 5.988175041974725e-05 | 1.495 | 0.0
4 | 13.503878899849951 | 2.0 | 2.00137072 | 0.00012179719331753966 | 2.001 | 0.0
5 | 17.045905499951914 | 2.5 | 2.5004275766666666 | 3.320902036094788e-05 | 2.5 | 0.0
6 | 19.180321499938145 | 3.0 | 2.99614027 | 1.550185472788275e-05 | 2.9949999999999997 | 0.0
7 | 21.309337900020182 | 3.5 | 3.504156483333334 | 0.00010629780634301851 | 3.503 | 0.0
8 | 23.452129499986768 | 4.0 | 4.0001674199999995 | 9.109506023707047e-06 | 4.0 | 0.0
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

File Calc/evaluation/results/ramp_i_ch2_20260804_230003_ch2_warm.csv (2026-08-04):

# timestamp: 2026-08-04T23:04:01
# quantity: current
# channel: 2
# psu_idn: PreReg | PSU-2CH-36V2A | SN00001 | 0.2.0
# dmm_idn: Siglent Technologies | SDM3065X | SDM36HCQ7R1239 | 3.02.01.12R1
# min_A: 0.0
# max_A: 2.0
# step_A: 0.025
# companion: 2.0
# settle_s: 0.6
# dmm_range: 2
# nplc: 10.0
# dmm_samples: 3
# psu_samples: 3
# simulated: False
index | t_s | v_set | v_dmm | v_dmm_sd | v_psu | aux_psu | temp_c
0 | 2.059404900064692 | 0.0 | 0.0005952096656666666 | 1.570852363417214e-05 | 0.0007 | 0.001 | 52.2
1 | 4.199661700055003 | 0.025 | 0.024798465966666666 | 1.0283589789723968e-05 | 0.024899999999999995 | 0.002 | 51.3
2 | 6.345965699991211 | 0.05 | 0.04994772636666667 | 1.1997627268893725e-05 | 0.05000000000000001 | 0.003 | 50.2
3 | 8.476307899923995 | 0.075 | 0.07485949616666666 | 4.534665957191002e-06 | 0.0749 | 0.004 | 49.5
4 | 10.62009990005754 | 0.1 | 0.10012750166666667 | 1.028376299480904e-05 | 0.10010000000000001 | 0.007 | 49.1
5 | 12.759684700053185 | 0.125 | 0.124979899 | 6.855457096362773e-06 | 0.125 | 0.008 | 48.8
6 | 14.895902700023726 | 0.15 | 0.14975214333333334 | 1.7135755989502414e-06 | 0.1497 | 0.011 | 48.4
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

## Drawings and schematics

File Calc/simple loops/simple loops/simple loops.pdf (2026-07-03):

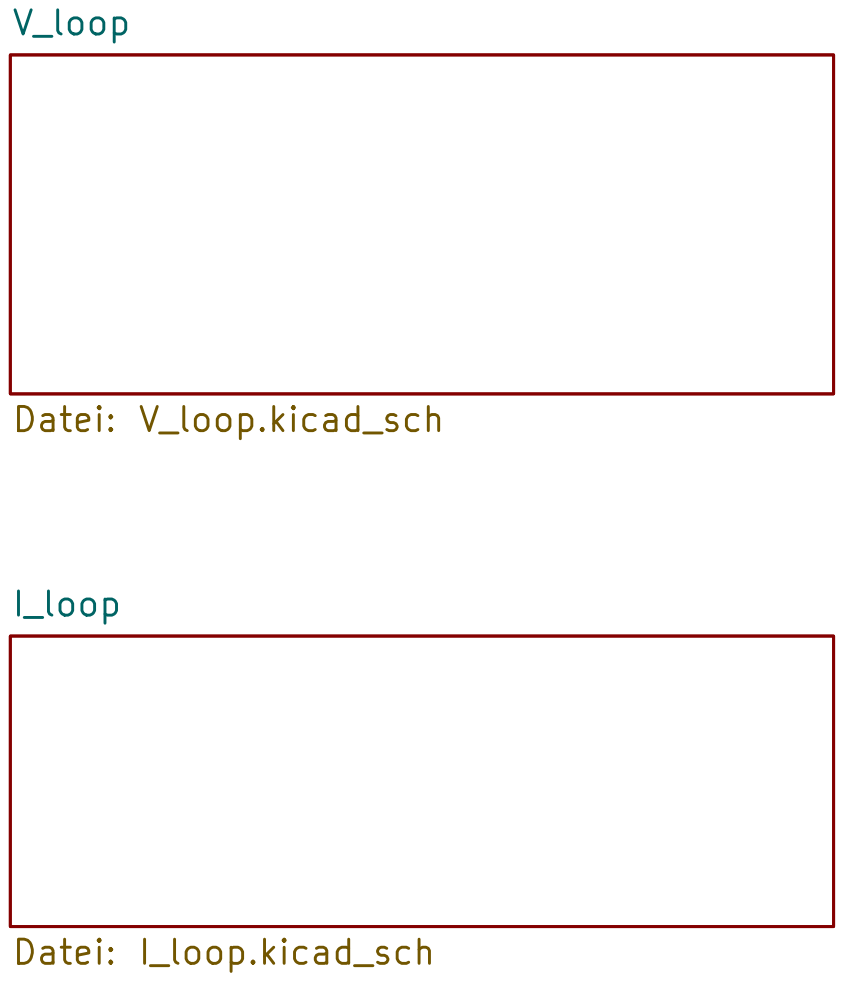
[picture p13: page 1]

Size: A4 | Rev:
KiCad E.D.A. 10.0.1 | Id: 1/3

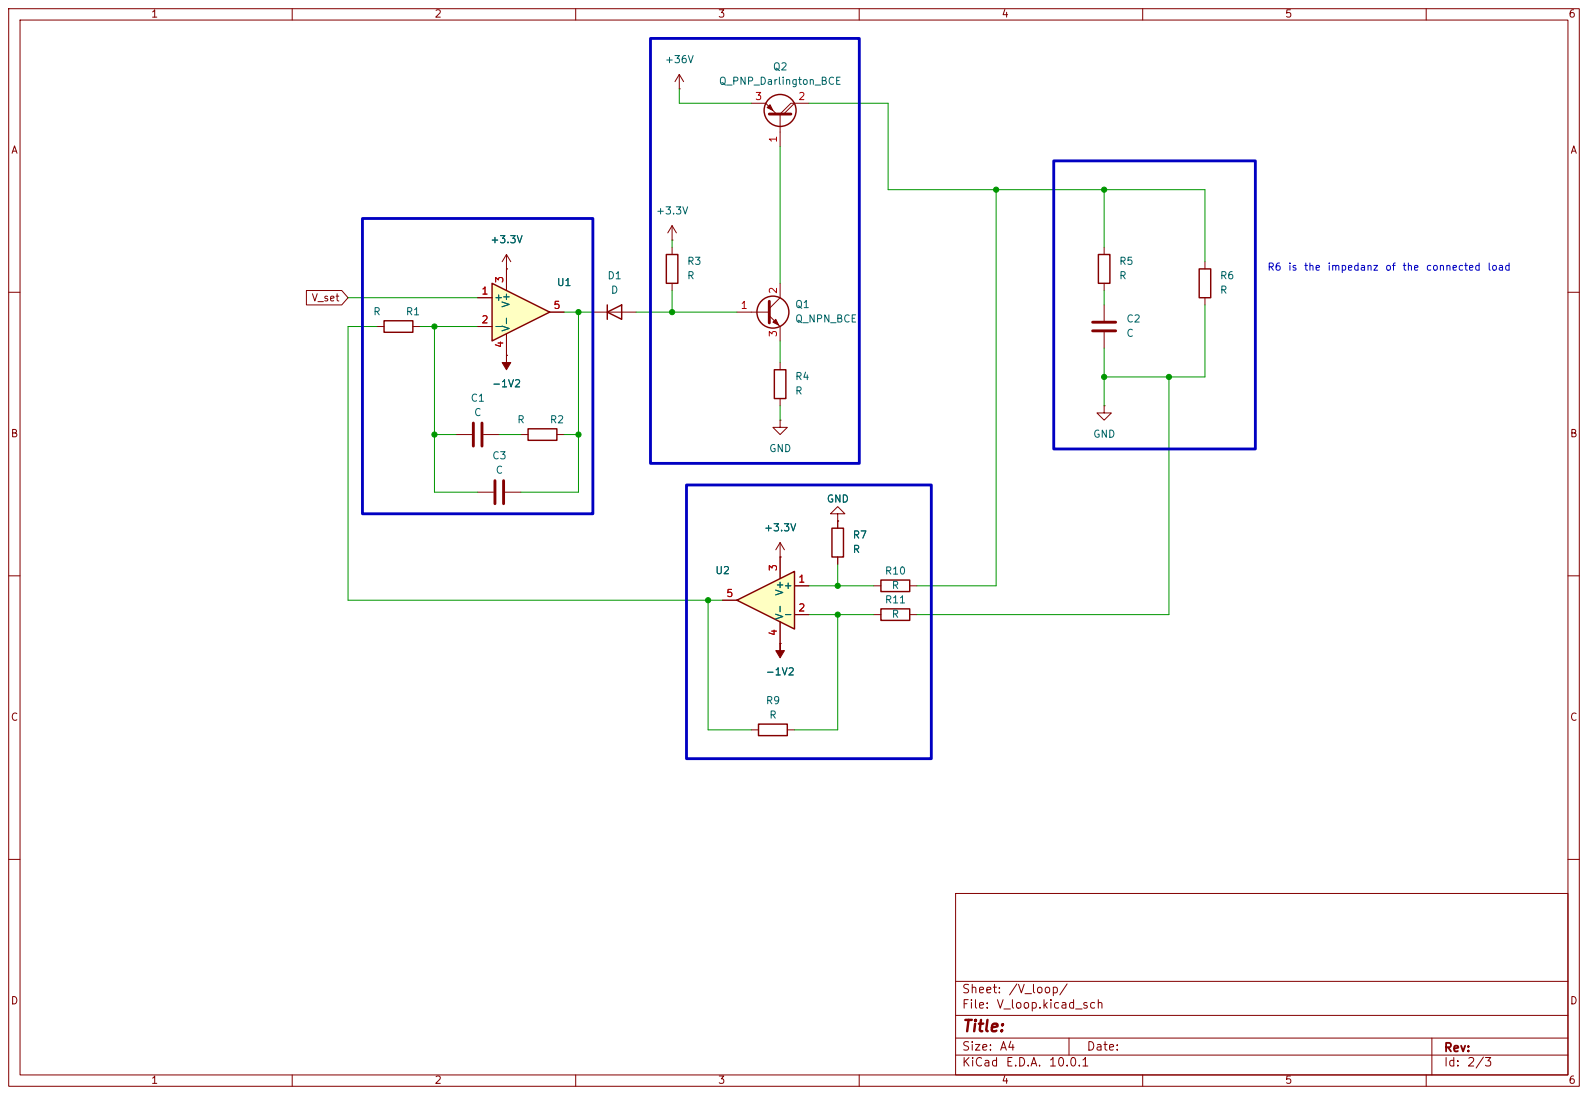
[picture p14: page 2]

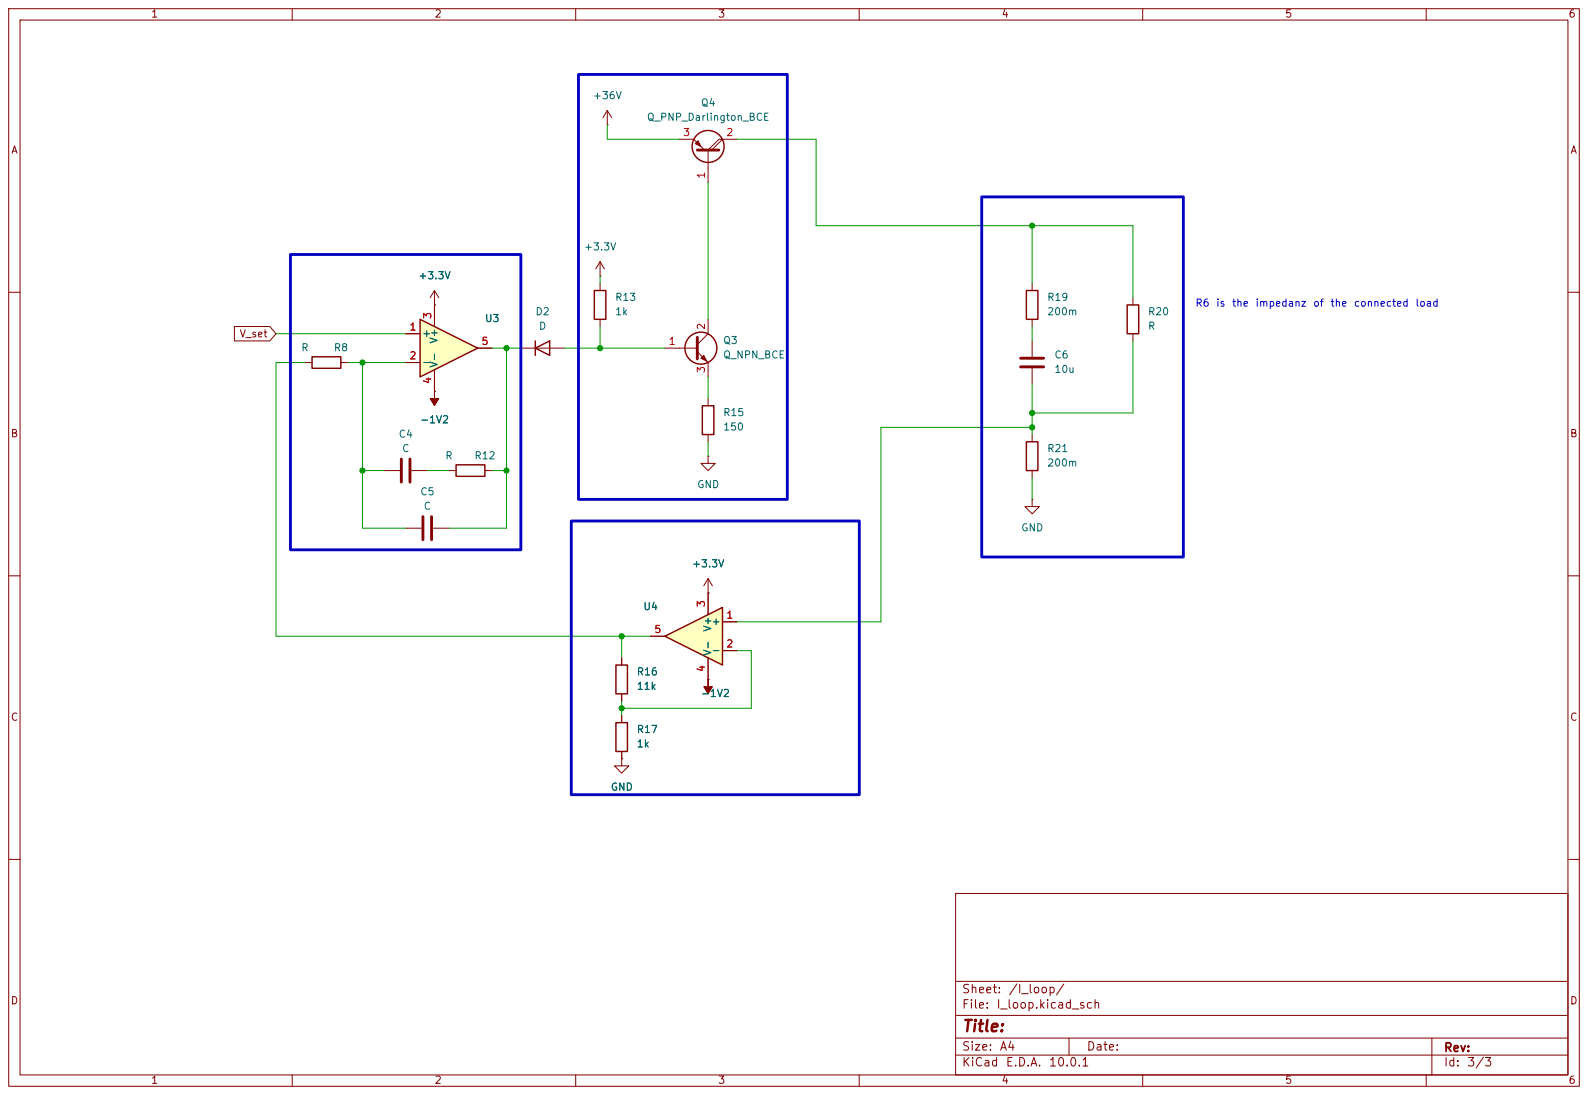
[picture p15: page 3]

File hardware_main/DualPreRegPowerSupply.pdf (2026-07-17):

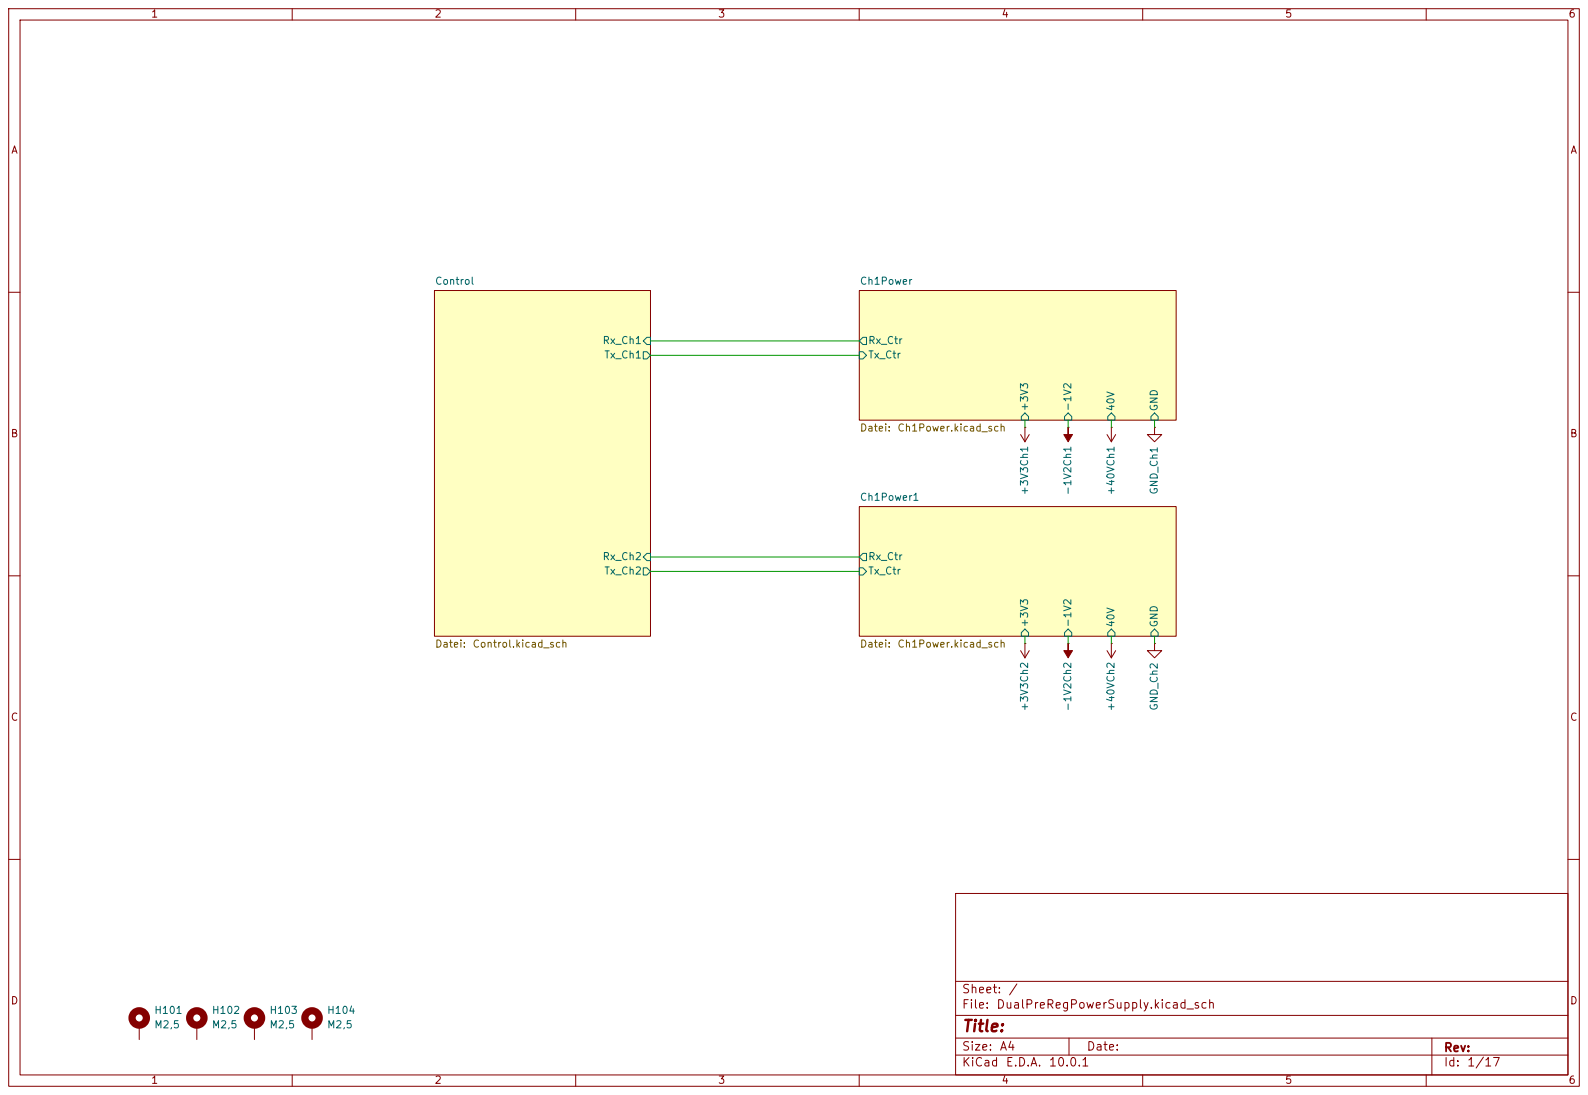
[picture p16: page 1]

Size: A4 | Rev:
KiCad E.D.A. 10.0.1 | Id: 1/17

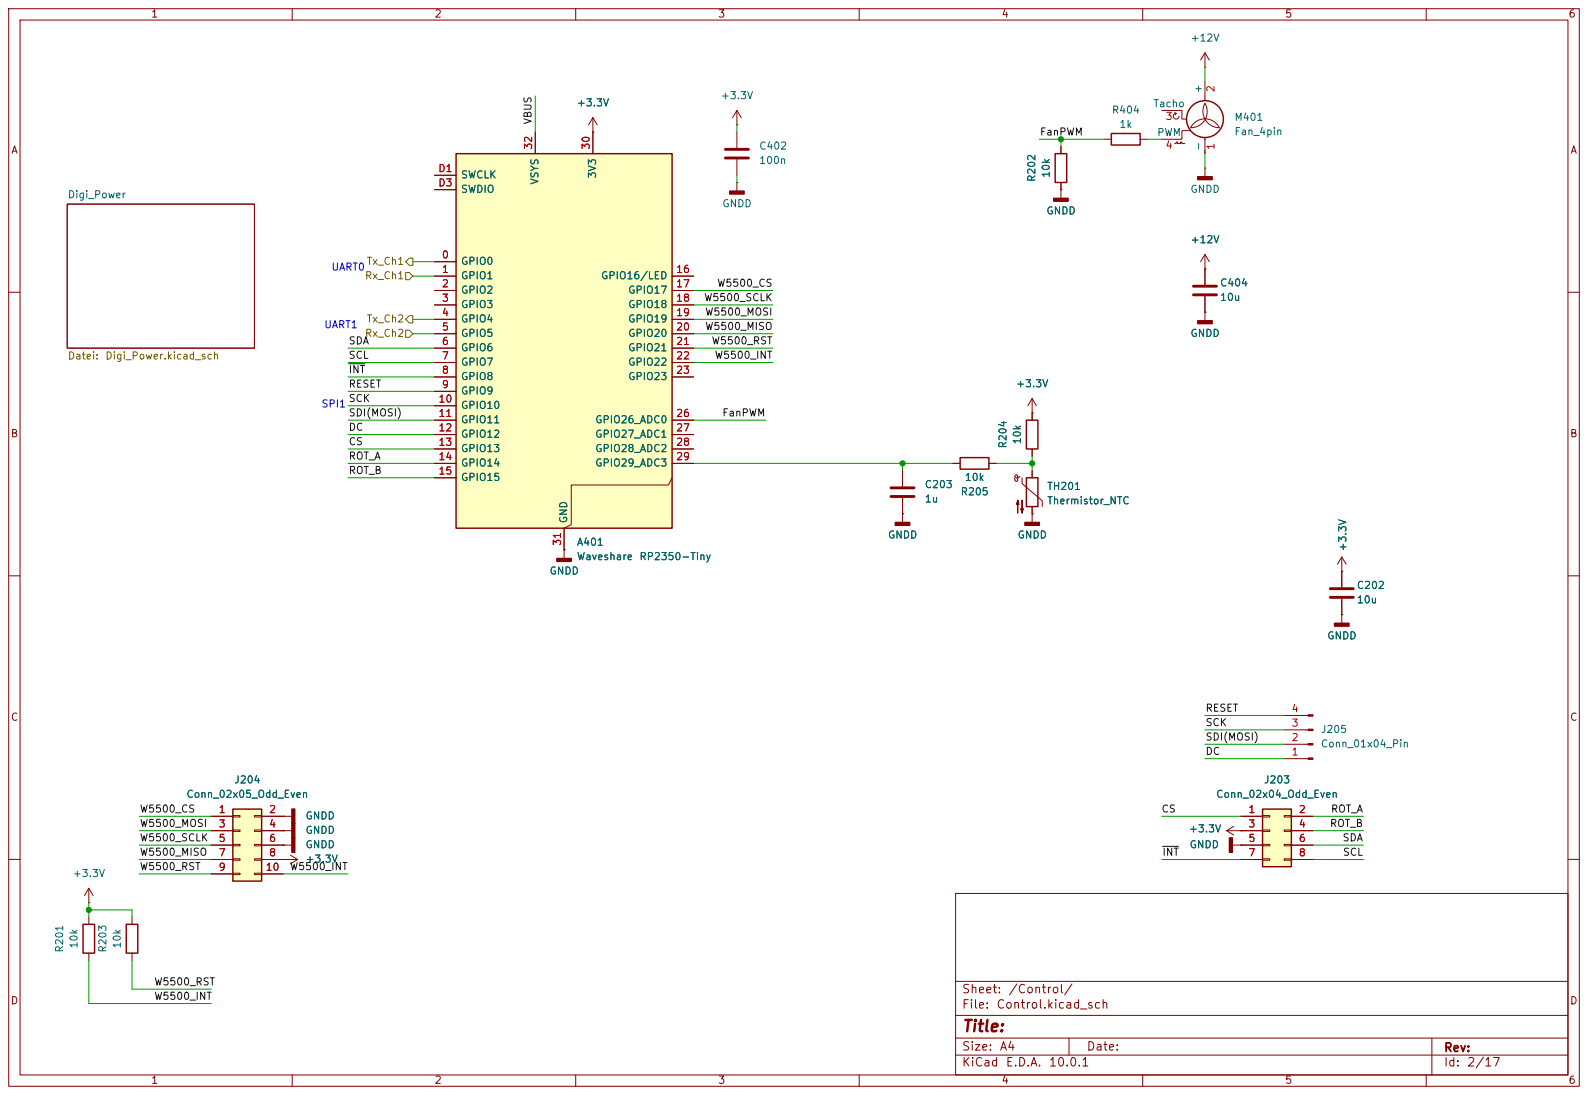
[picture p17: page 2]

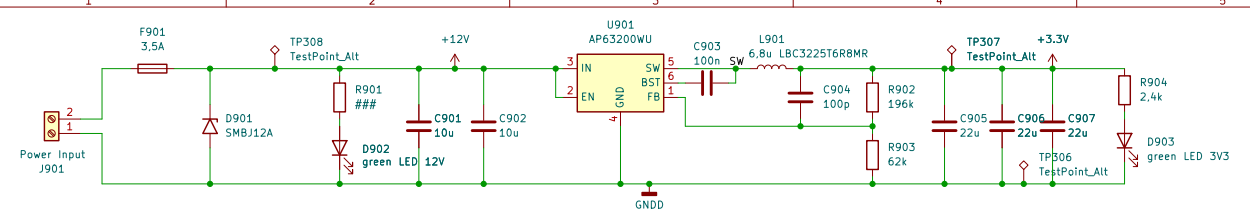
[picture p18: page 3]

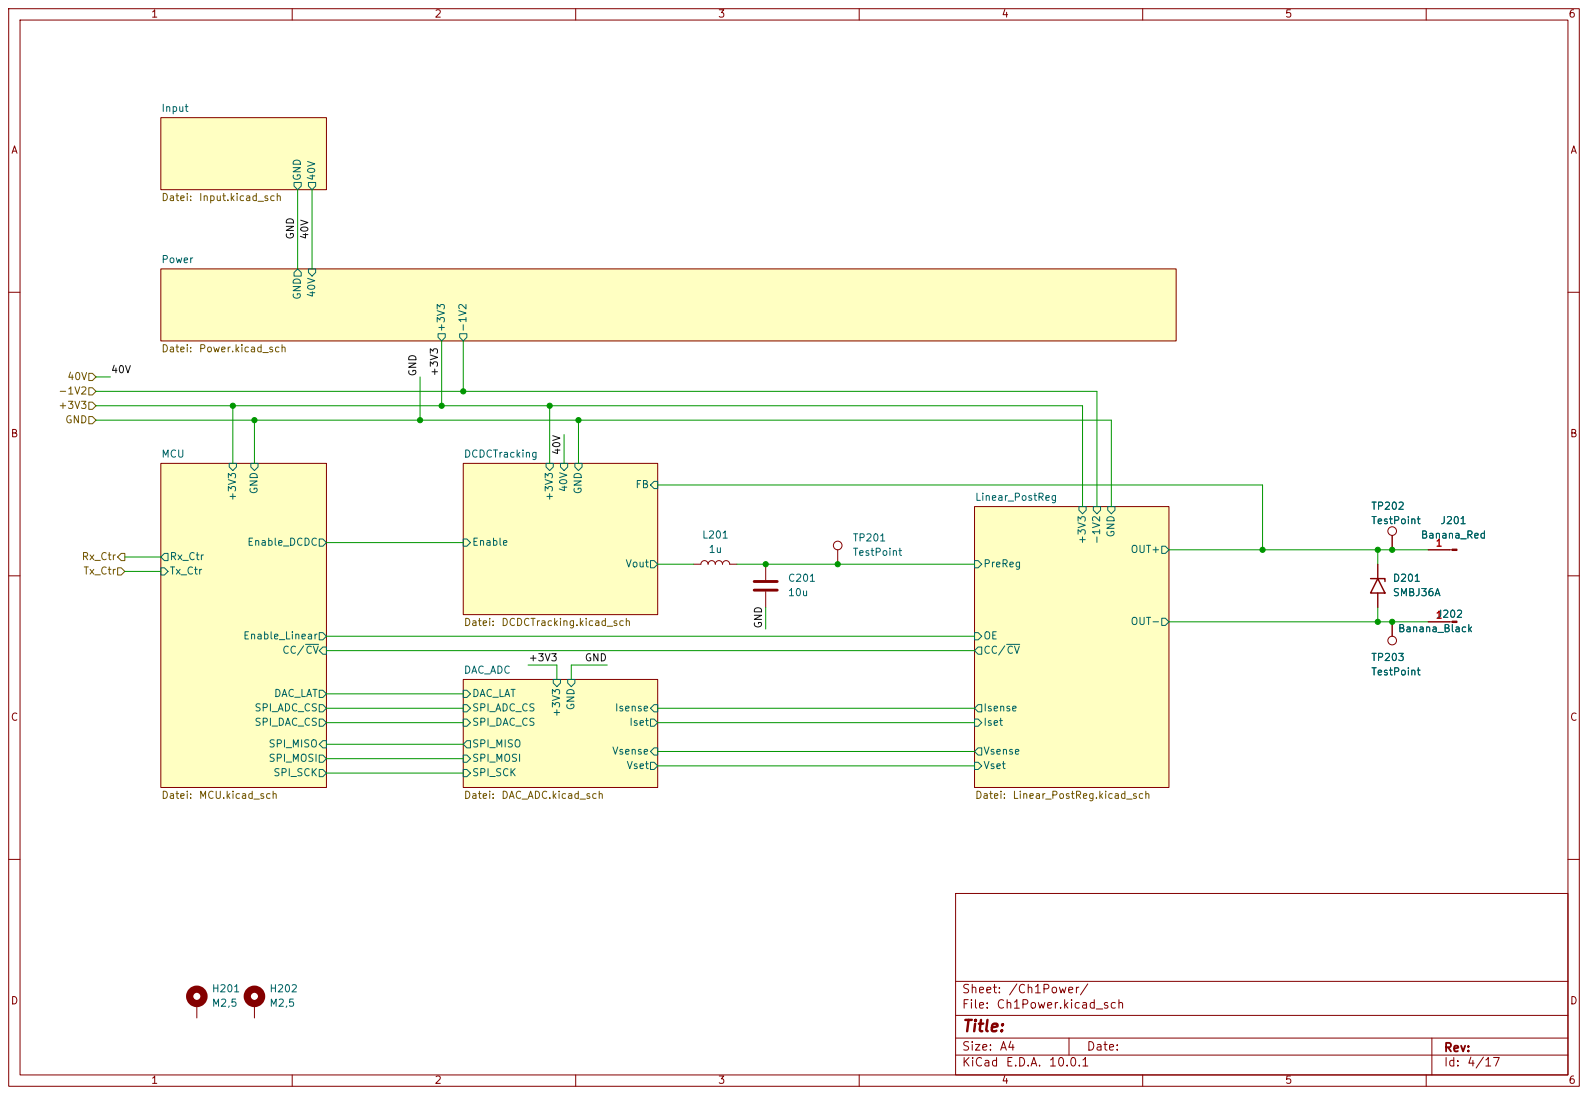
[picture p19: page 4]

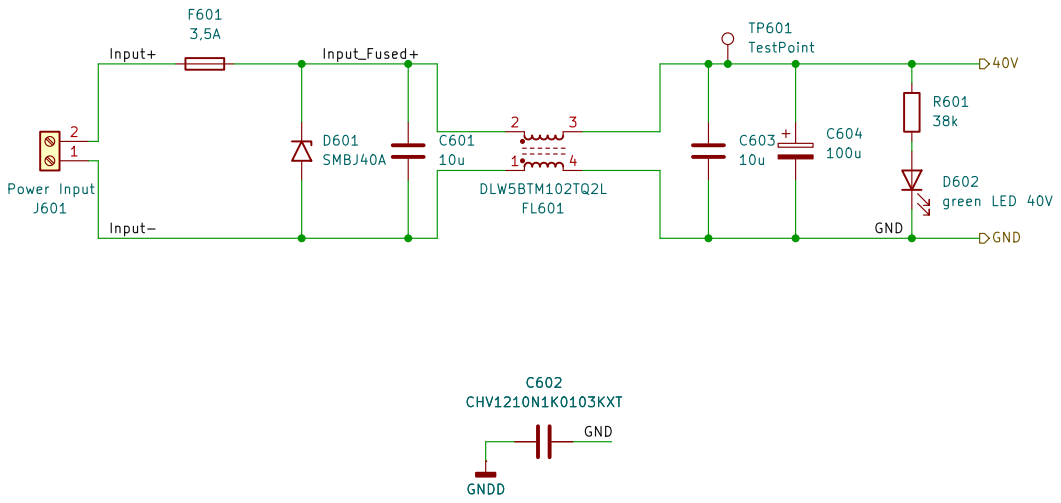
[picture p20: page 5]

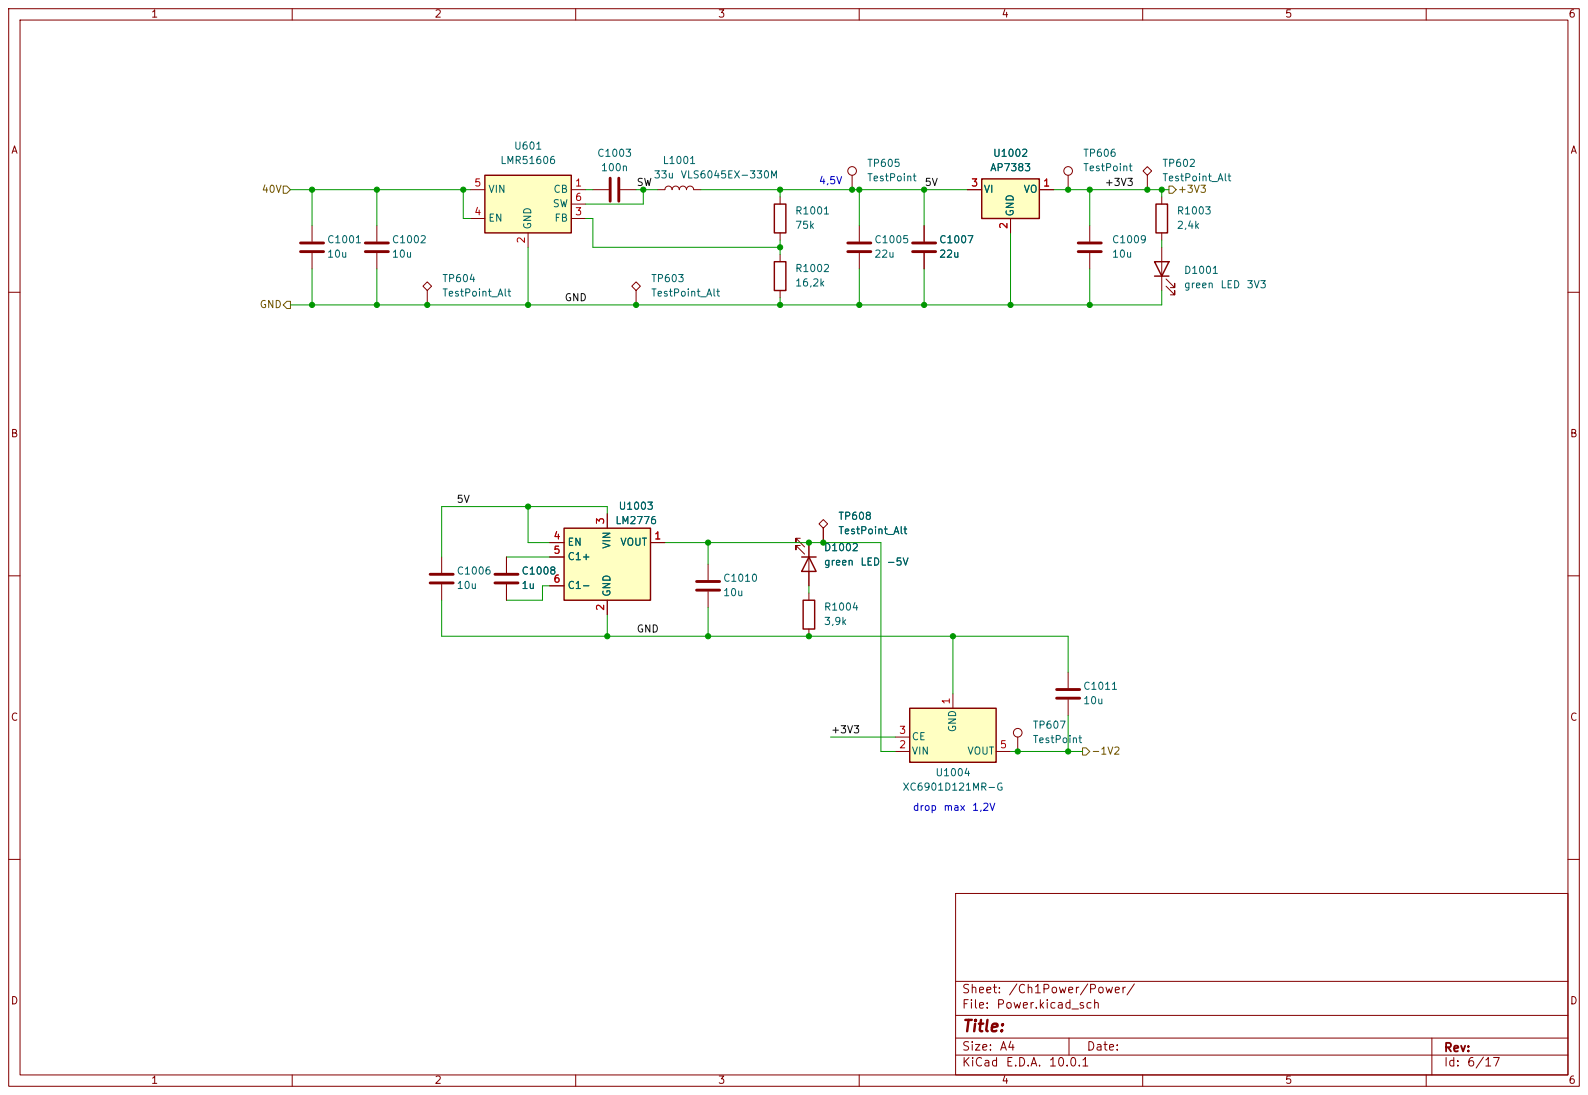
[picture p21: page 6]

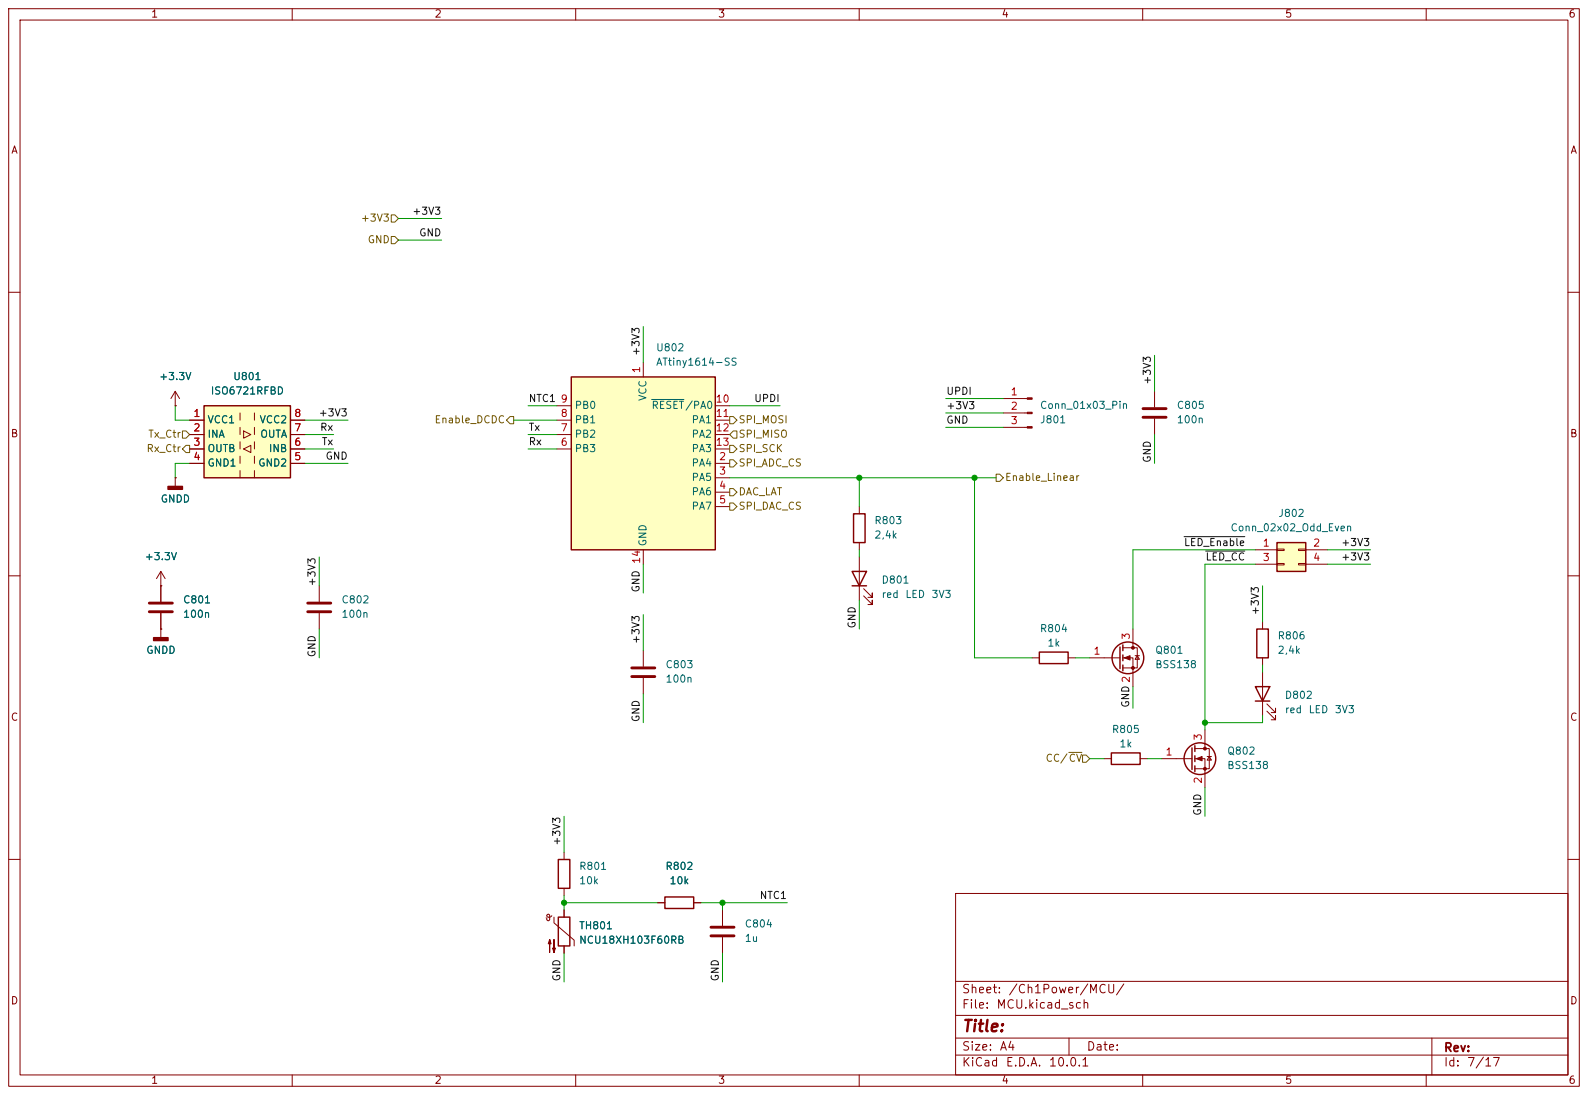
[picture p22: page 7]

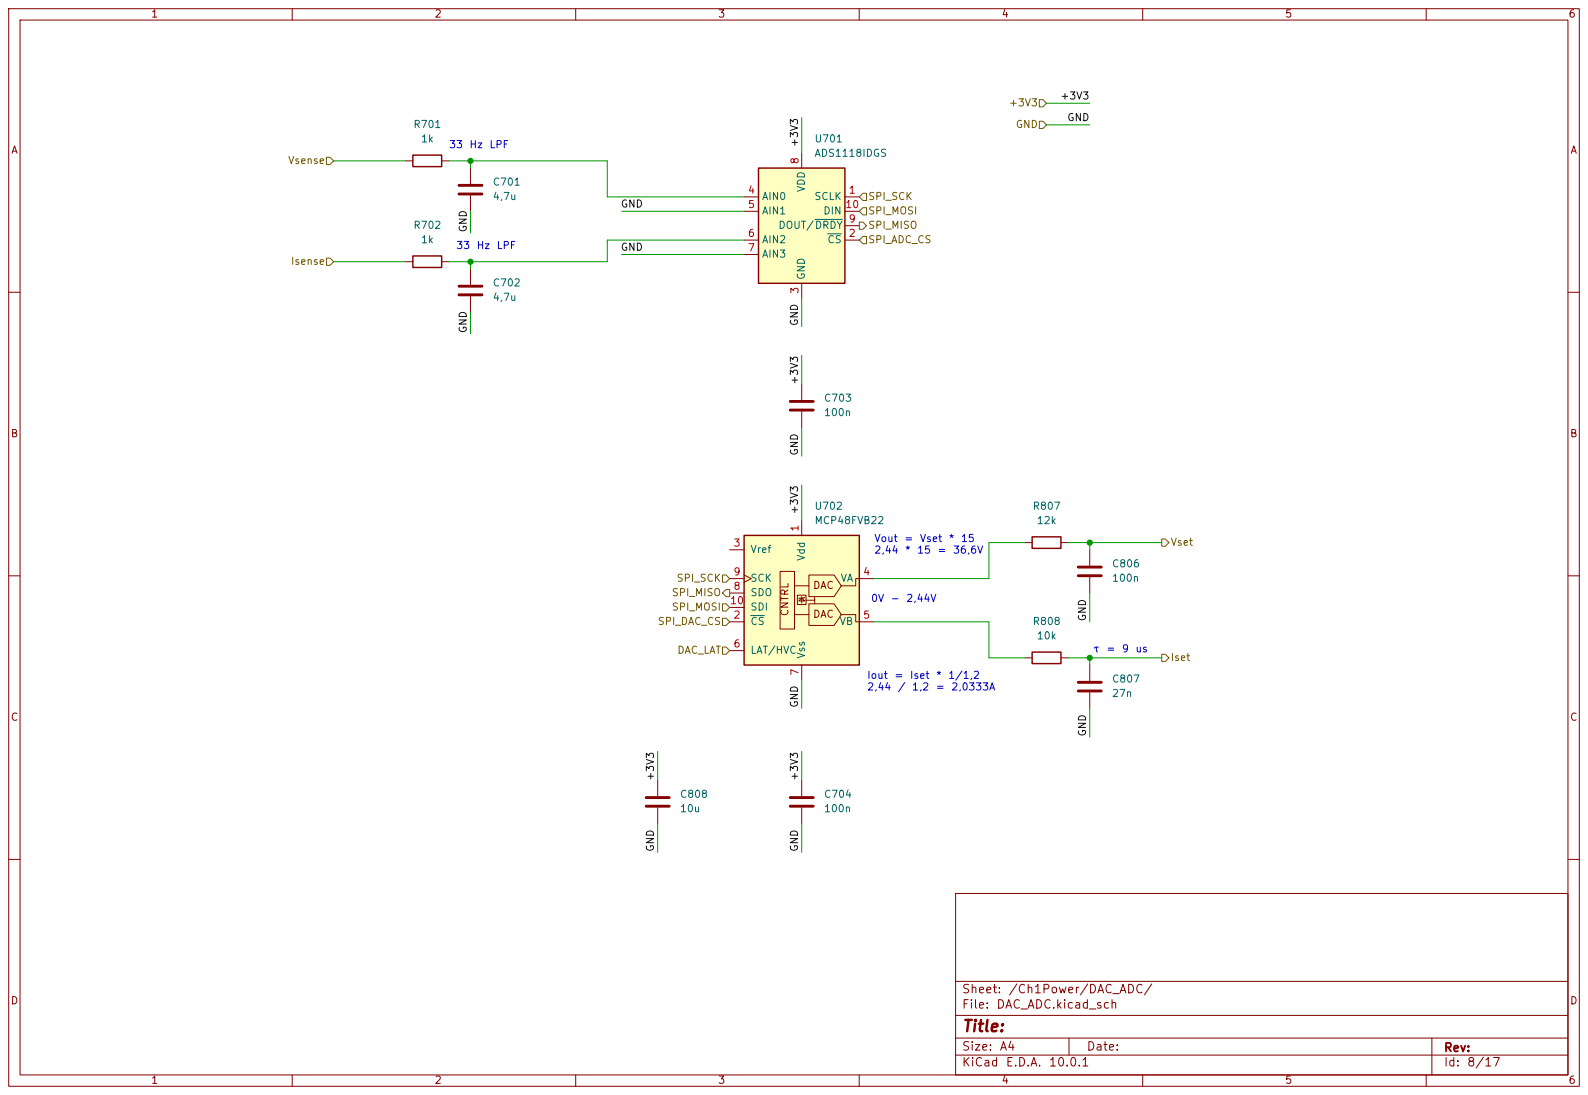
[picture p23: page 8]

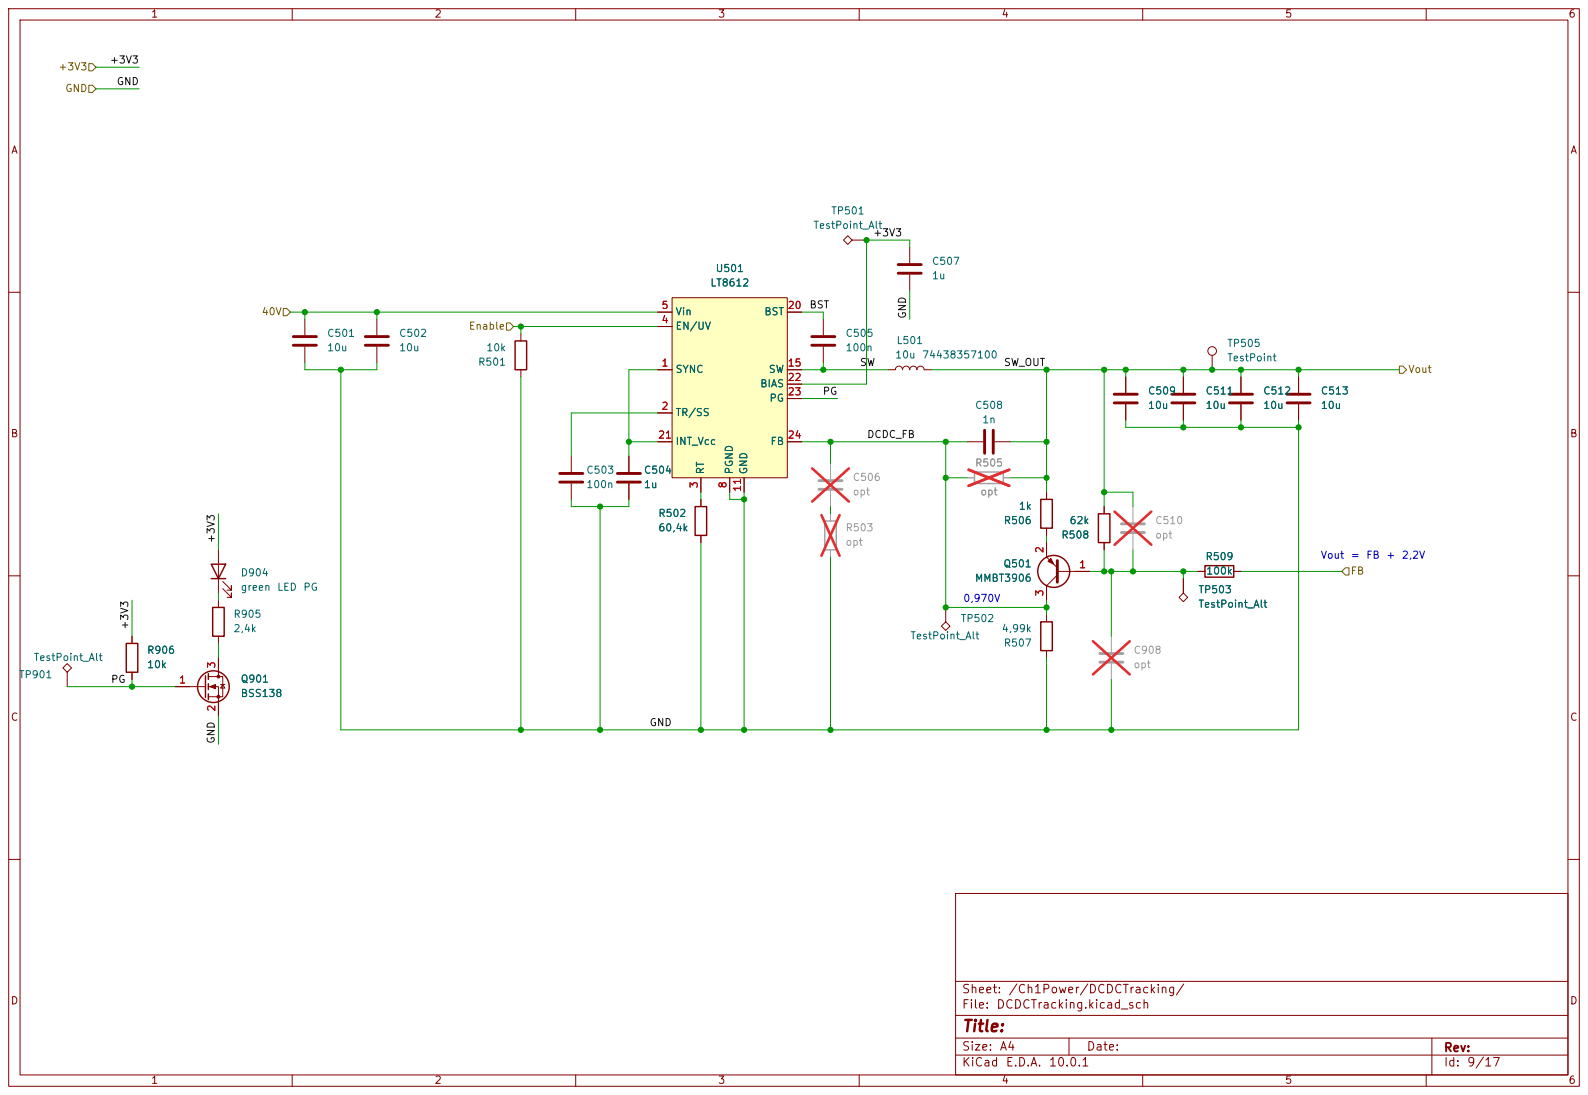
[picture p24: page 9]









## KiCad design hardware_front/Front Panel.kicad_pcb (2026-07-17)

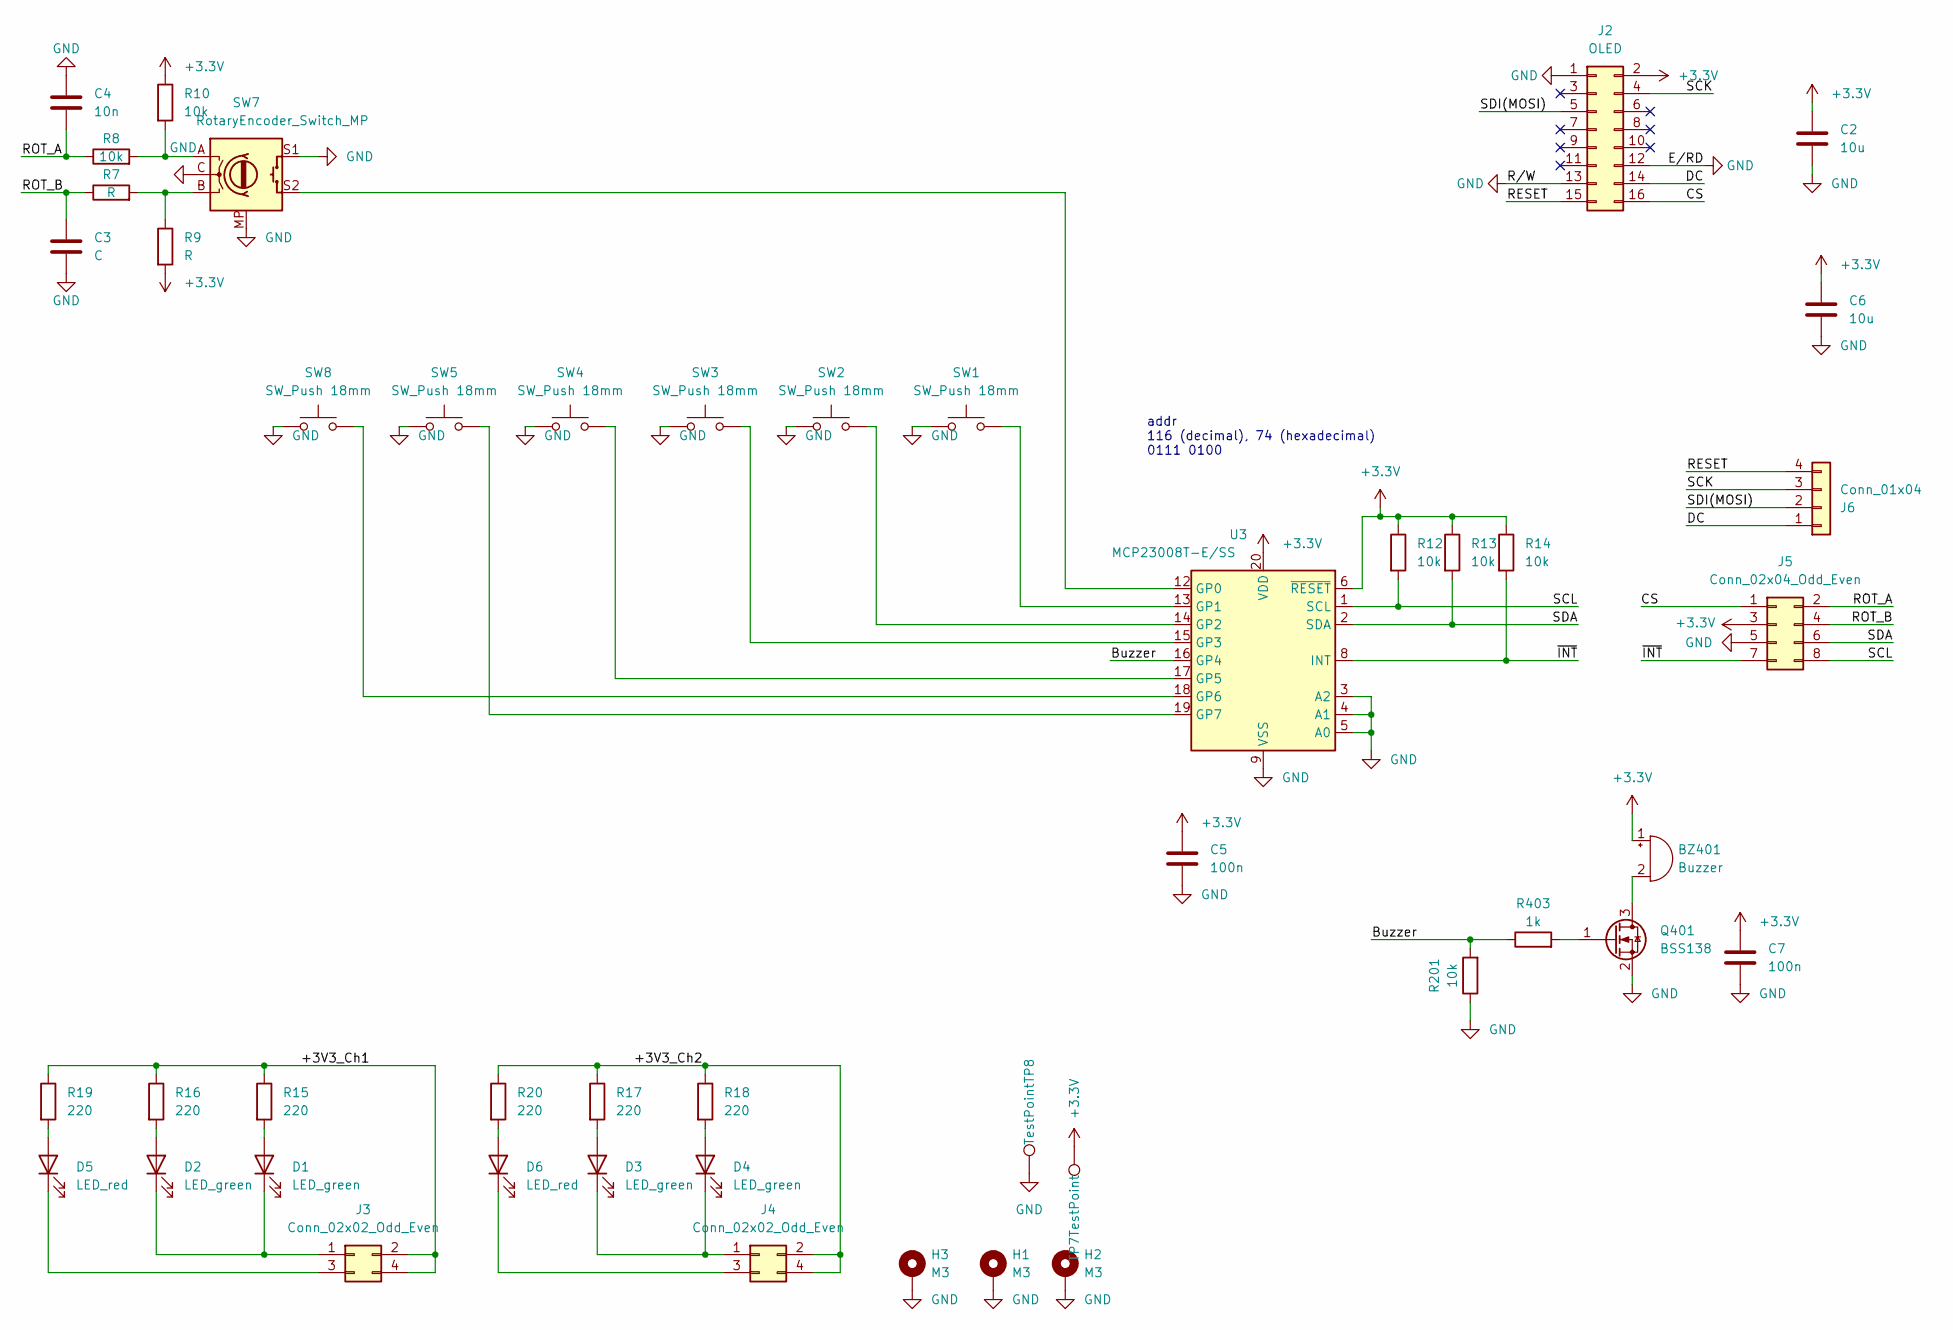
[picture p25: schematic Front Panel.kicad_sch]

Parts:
BZ401: Buzzer; Buzzer_12x9.5RM7.6
C2, C6: 10u; C_0805_2012Metric
C3: C; C_0603_1608Metric
C4: 10n; C_0603_1608Metric
C5, C7: 100n; C_0603_1608Metric
D1, D2, D3, D4: LED_green; LED_D3.0mm_FlatTop
D5, D6: LED_red; LED_D3.0mm_FlatTop
H1, H2, H3: M3; MountingHole_3.2mm_M3_DIN965_Pad
J2: OLED; PinSocket_2x08_P2.54mm_Vertical
J3, J4: Conn_02x02_Odd_Even; PinSocket_2x02_P2.54mm_Vertical
J5: Conn_02x04_Odd_Even; PinSocket_2x04_P2.54mm_Vertical
J6: Conn_01x04; PinSocket_1x04_P2.54mm_Vertical
Q401: BSS138; SOT-23-3
R7, R9: R; R_0603_1608Metric
R8, R10, R12, R13, R14, R201: 10k; R_0603_1608Metric
R15, R16, R17, R18, R19, R20: 220; R_0603_1608Metric
R403: 1k; R_0603_1608Metric
SW1, SW2, SW3, SW4, SW5, SW8: SW_Push 18mm; SW_PUSH_6mm_H13mm
SW7: RotaryEncoder_Switch_MP; RotaryEncoder_Alps_EC11E-Switch_Vertical_H20mm
TP7, TP8: TestPoint; TestPoint_Pad_D1.5mm
U3: MCP23008T-E/SS; SSOP-20_5.3x7.2mm_P0.65mm

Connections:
+3.3V: BZ401.1 (+), C2.1, C5.1, C6.1, C7.1, J2.2, J5.3, R9.2, R10.1, R12.1, R13.1, R14.1, TP7.1 (1_1), U3.6 (~RESET), U3.20 (VDD)
/+3V3_Ch1: J3.2, J3.4, R15.1, R16.1, R19.1
/+3V3_Ch2: J4.2, J4.4, R17.1, R18.1, R20.1
/Buzzer: R201.2, R403.1, U3.16 (GP4)
/CS: J2.16, J5.1
/DC: J2.14, J6.1
/RESET: J2.15, J6.4
/ROT_A: C4.1, J5.2, R8.1
/ROT_B: C3.1, J5.4, R7.1
/SCK: J2.4, J6.3
/SCL: J5.8, R12.2, U3.1 (SCL)
/SDA: J5.6, R13.2, U3.2 (SDA)
/SDI(MOSI): J2.5, J6.2
/~INT: J5.7, R14.2, U3.8 (INT)
GND: C2.2, C3.2, C4.2, C5.2, C6.2, C7.2, H1.1 (1_1), H2.1 (1_1), H3.1 (1_1), J2.1, J2.12, J2.13, J5.5, Q401.2 (S), R201.1, SW1.1, SW2.1, SW3.1, SW4.1, SW5.1, SW7.C, SW7.MP, SW7.S1, SW8.1, TP8.1 (1_1), U3.3 (A2), U3.4 (A1), U3.5 (A0), U3.9 (VSS)
unnamed: BZ401.2 (-), Q401.3 (D)
unnamed: D1.2 (A), R15.2
unnamed: D1.1 (K), D2.1 (K), J3.1
unnamed: D2.2 (A), R16.2
unnamed: D3.2 (A), R17.2
unnamed: D3.1 (K), D4.1 (K), J4.1
unnamed: D4.2 (A), R18.2
unnamed: D5.2 (A), R19.2
unnamed: D5.1 (K), J3.3
unnamed: D6.2 (A), R20.2
unnamed: D6.1 (K), J4.3
unnamed: Q401.1 (G), R403.2
unnamed: R7.2, R9.1, SW7.B
unnamed: R8.2, R10.2, SW7.A
unnamed: SW7.S2, U3.12 (GP0)
unnamed: SW1.2, U3.13 (GP1)
unnamed: SW2.2, U3.14 (GP2)
unnamed: SW3.2, U3.15 (GP3)
unnamed: SW4.2, U3.17 (GP5)
unnamed: SW8.2, U3.18 (GP6)
unnamed: SW5.2, U3.19 (GP7)

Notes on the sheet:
addr 116 (decimal), 74 (hexadecimal) 0111 0100

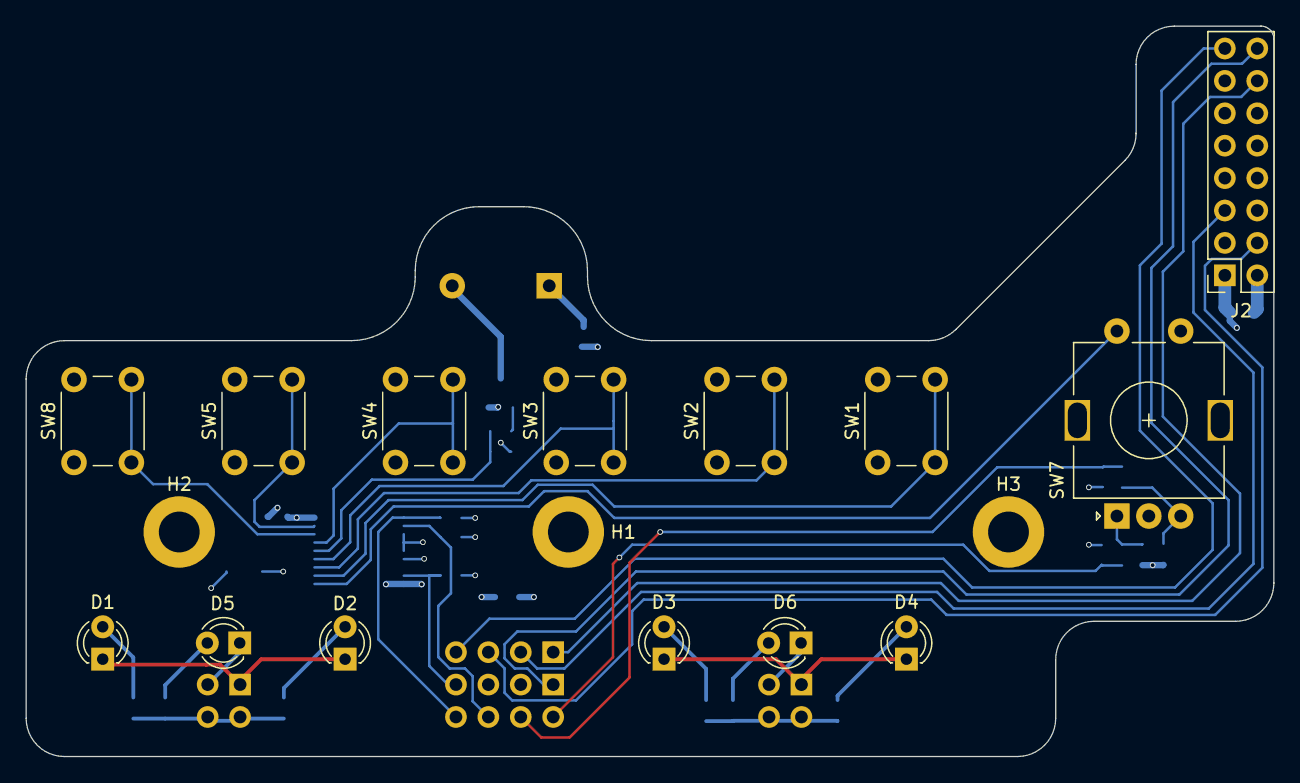
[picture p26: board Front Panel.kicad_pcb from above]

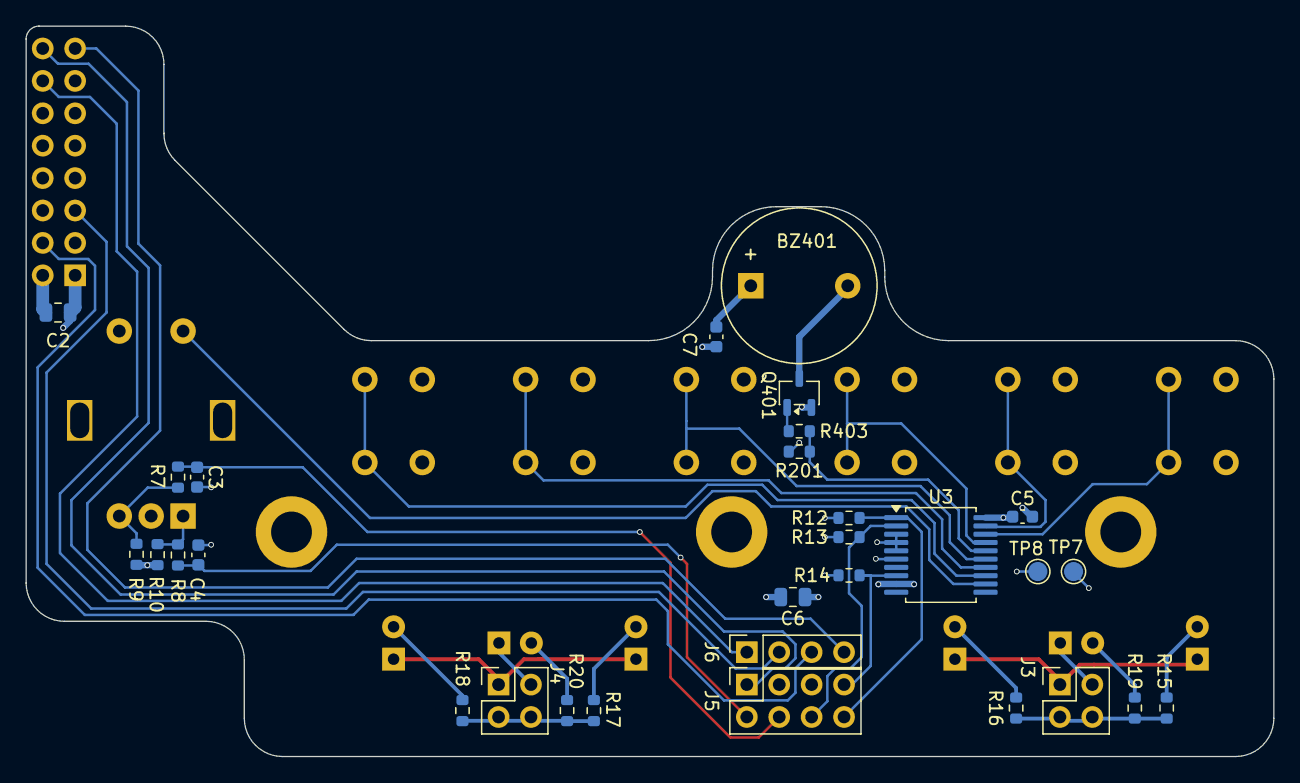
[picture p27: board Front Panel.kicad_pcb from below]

Board: 4 copper layers, 97.8 x 57.2 mm, 47 parts (30 on the bottom side), 36 nets.

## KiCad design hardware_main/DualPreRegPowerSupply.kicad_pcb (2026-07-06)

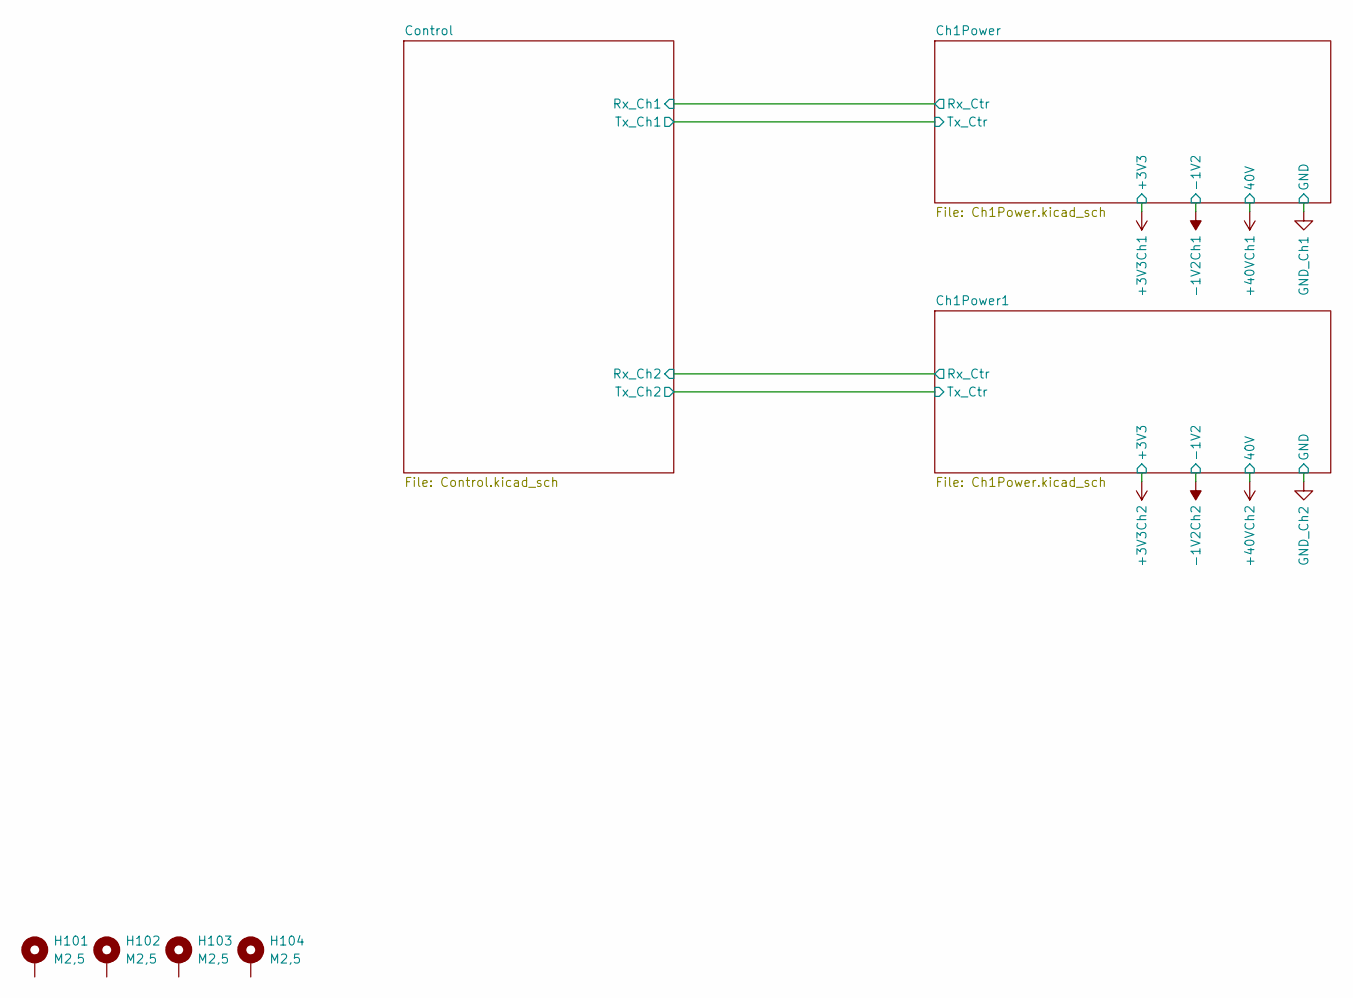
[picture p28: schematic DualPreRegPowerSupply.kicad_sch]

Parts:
H101, H102, H103, H104: M2,5; MountingHole_2.7mm_M2.5_DIN965_Pad

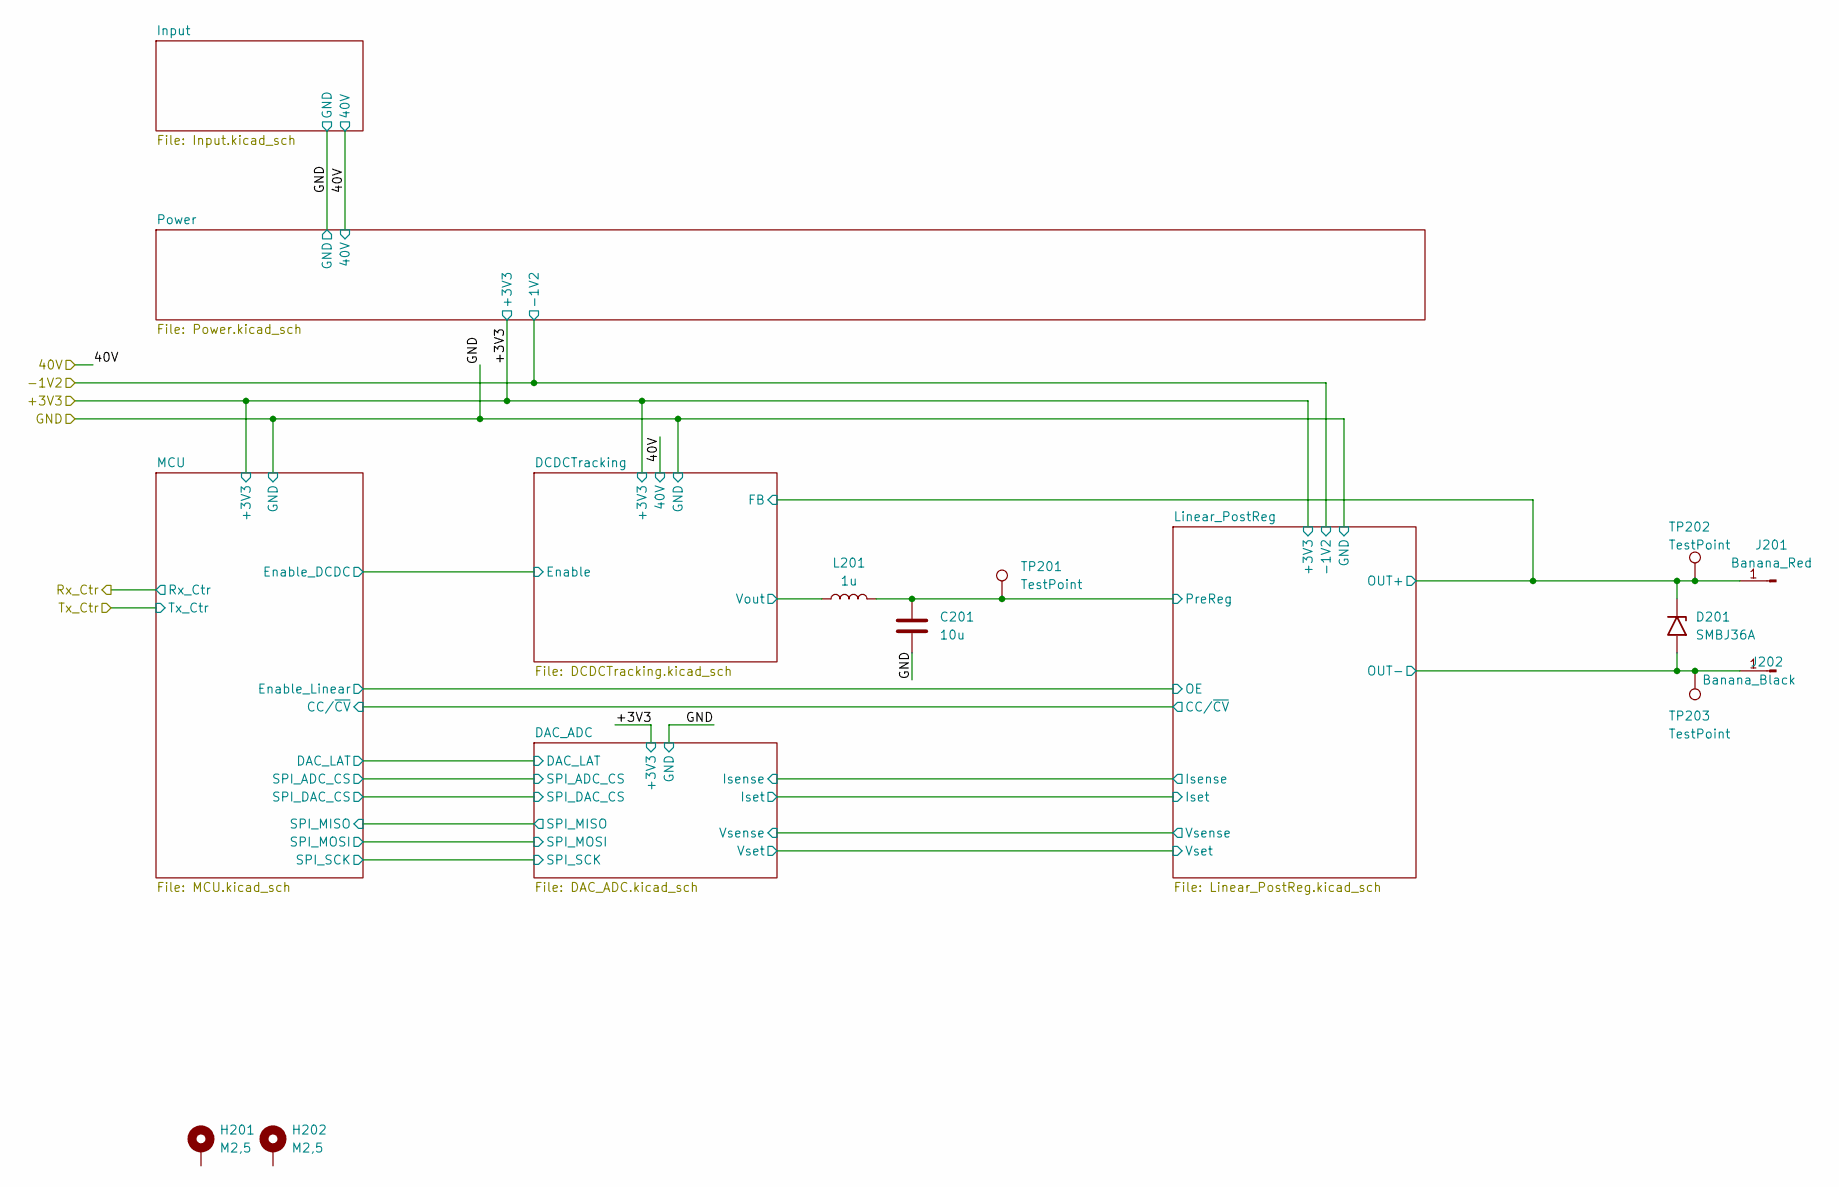
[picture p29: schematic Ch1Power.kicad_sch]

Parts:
C201: 10u; C_1206_3216Metric
D201: SMBJ36A; D_SMB
H201, H202: M2,5; MountingHole_2.7mm_M2.5_DIN965_Pad
J201: Banana_Red; Banana_Cliff_FCR7350R_S16N-PC_Horizontal
J202: Banana_Black; Banana_Cliff_FCR7350B_S16N-PC_Horizontal
L201: 1u; L_0805_2012Metric
TP201, TP202, TP203: TestPoint; SMD Test Point PCWCTE

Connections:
/Ch1Power/DCDCTracking/SW_OUT: L201.1; also elsewhere on the board
/Ch1Power/Linear_PostReg/OUT+: D201.1 (A1), J201.1 (Pin_1_1), TP202.1 (1_1); also elsewhere on the board
/Ch1Power/Linear_PostReg/OUT-: D201.2 (A2), J202.1 (Pin_1_1), TP203.1 (1_1); also elsewhere on the board
/Ch1Power/Linear_PostReg/PreReg: C201.1, L201.2, TP201.1 (1_1); also elsewhere on the board
GND_Ch1: C201.2; also elsewhere on the board

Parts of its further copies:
C405: 10u; C_1206_3216Metric
D401: SMBJ36A; D_SMB
H401, H402: M2,5; MountingHole_2.7mm_M2.5_DIN965_Pad
J402: Banana_Red; Banana_Cliff_FCR7350R_S16N-PC_Horizontal
J403: Banana_Black; Banana_Cliff_FCR7350B_S16N-PC_Horizontal
L401: 1u; L_0805_2012Metric
TP401, TP402, TP403: TestPoint; SMD Test Point PCWCTE

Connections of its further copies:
/Ch1Power1/DCDCTracking/SW_OUT: L401.1; also elsewhere on the board
/Ch1Power1/Linear_PostReg/OUT+: D401.1 (A1), J402.1 (Pin_1_1), TP402.1 (1_1); also elsewhere on the board
/Ch1Power1/Linear_PostReg/OUT-: D401.2 (A2), J403.1 (Pin_1_1), TP403.1 (1_1); also elsewhere on the board
/Ch1Power1/Linear_PostReg/PreReg: C405.1, L401.2, TP401.1 (1_1); also elsewhere on the board
GND_Ch2: C405.2; also elsewhere on the board

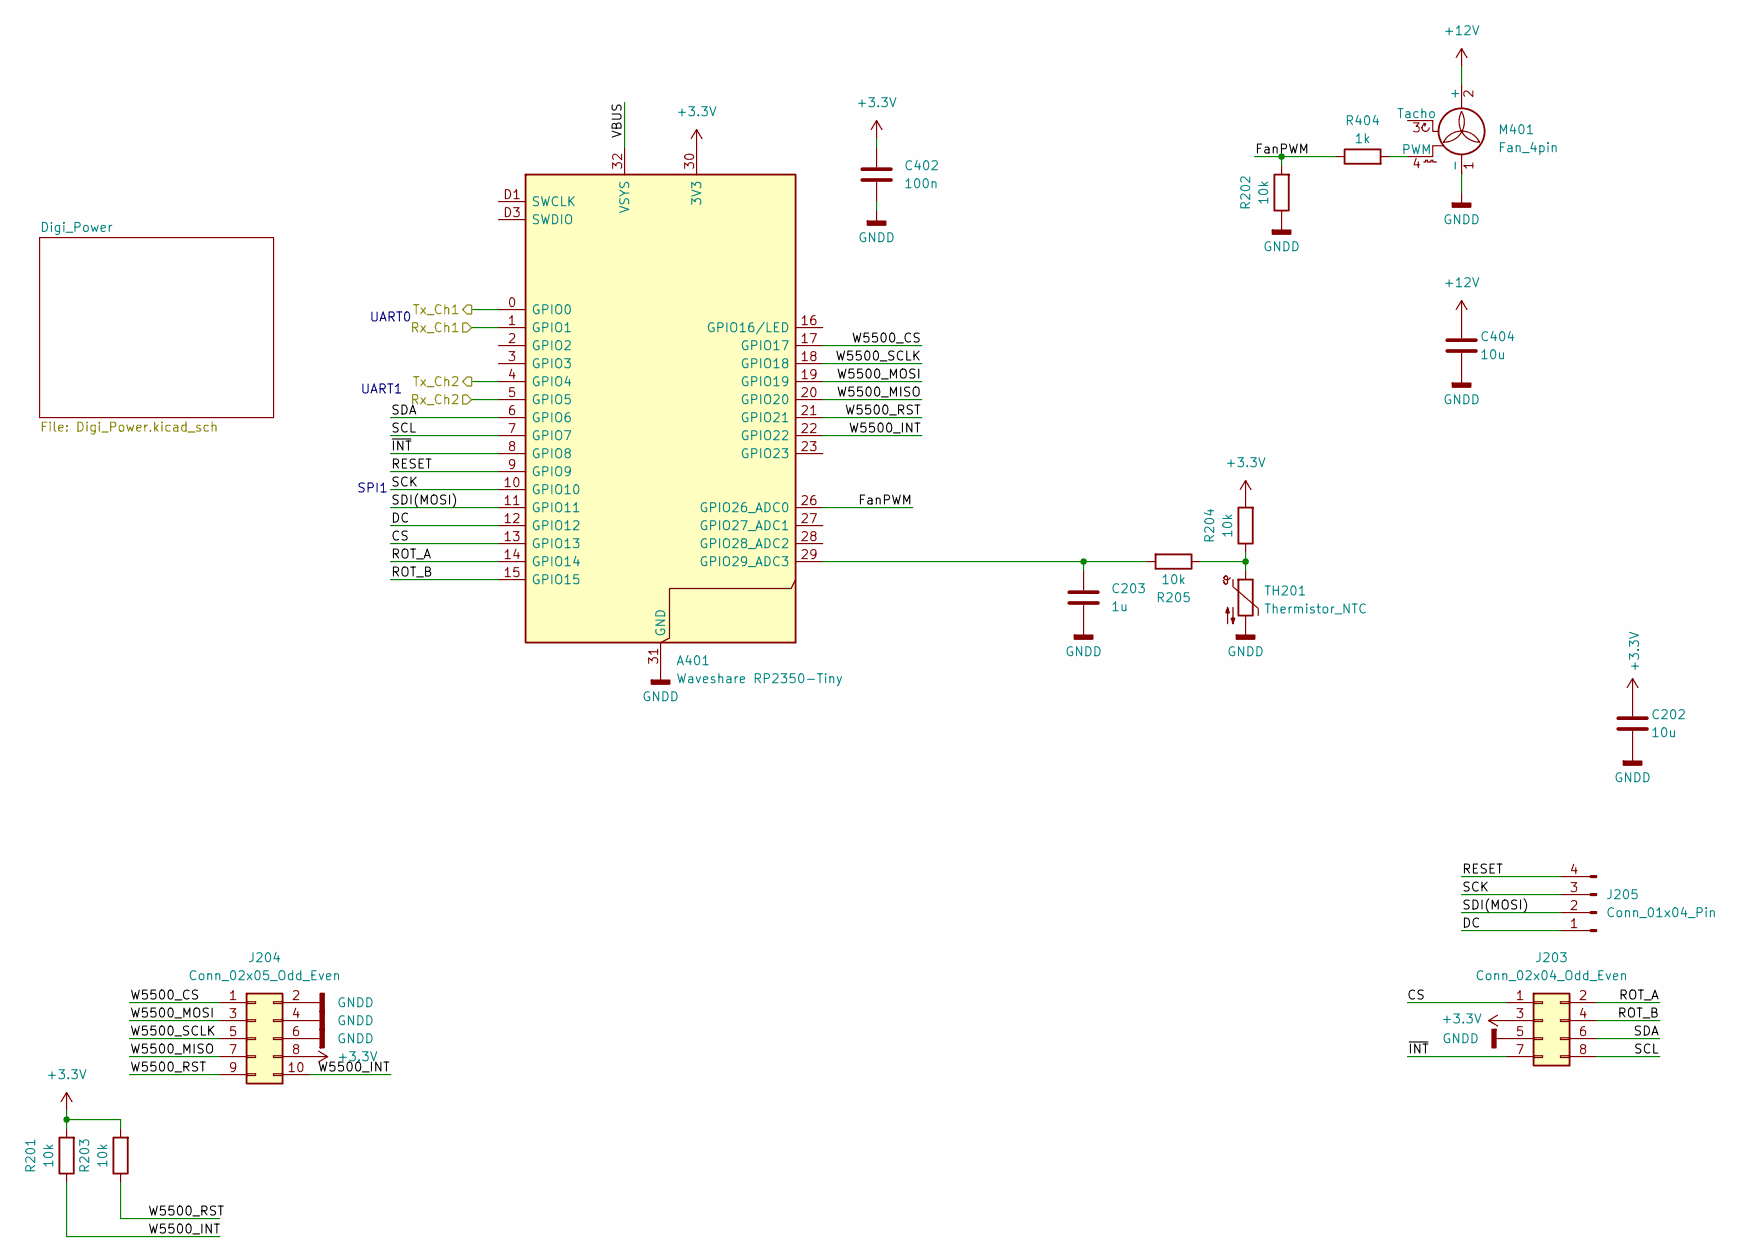
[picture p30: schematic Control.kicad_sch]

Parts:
A401: Waveshare RP2350-Tiny; Waveshare_PR2350_tiny
C202, C404: 10u; C_0805_2012Metric
C203: 1u; C_0603_1608Metric
C402: 100n; C_0603_1608Metric
J203: Conn_02x04_Odd_Even; PinHeader_2x04_P2.54mm_Horizontal
J204: Conn_02x05_Odd_Even; IDC-Header_2x05_P2.54mm_Vertical
J205: Conn_01x04_Pin; PinHeader_1x04_P2.54mm_Vertical
M401: Fan_4pin; FanPinHeader_1x04_P2.54mm_Vertical
R201, R202, R203, R204, R205: 10k; R_0603_1608Metric
R404: 1k; R_0603_1608Metric
TH201: Thermistor_NTC; Flex NTC

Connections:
+3.3V: A401.30 (3V3), A401.35 (3V3), C202.1, C402.1, J203.3, J204.8, R201.2, R203.2, R204.2; also elsewhere on the board
+12V: C404.1, M401.2 (+); also elsewhere on the board
/Ch1Power1/Rx_Ctr: A401.5 (GPIO5); also elsewhere on the board
/Ch1Power1/Tx_Ctr: A401.4 (GPIO4); also elsewhere on the board
/Ch1Power/Rx_Ctr: A401.1 (GPIO1); also elsewhere on the board
/Ch1Power/Tx_Ctr: A401.0 (GPIO0); also elsewhere on the board
/Control/CS: A401.13 (GPIO13), J203.1
/Control/DC: A401.12 (GPIO12), J205.1
/Control/FanPWM: A401.26 (GPIO26_ADC0), R202.2, R404.1
/Control/RESET: A401.9 (GPIO9), J205.4
/Control/ROT_A: A401.14 (GPIO14), J203.2
/Control/ROT_B: A401.15 (GPIO15), J203.4
/Control/SCK: A401.10 (GPIO10), J205.3
/Control/SCL: A401.7 (GPIO7), J203.8
/Control/SDA: A401.6 (GPIO6), J203.6
/Control/SDI(MOSI): A401.11 (GPIO11), J205.2
/Control/VBUS: A401.32 (VSYS)
/Control/W5500_CS: A401.17 (GPIO17), J204.1
/Control/W5500_INT: A401.22 (GPIO22), J204.10, R201.1
/Control/W5500_MISO: A401.20 (GPIO20), J204.7
/Control/W5500_MOSI: A401.19 (GPIO19), J204.3
/Control/W5500_RST: A401.21 (GPIO21), J204.9, R203.1
/Control/W5500_SCLK: A401.18 (GPIO18), J204.5
/Control/~INT: A401.8 (GPIO8), J203.7
GNDD: A401.31 (GND), A401.34 (GND), A401.D2 (GND), C202.2, C203.2, C402.2, C404.2, J203.5, J204.2, J204.4, J204.6, M401.1 (-), R202.1, TH201.2; also elsewhere on the board
unnamed: A401.29 (GPIO29_ADC3), C203.1, R205.2
unnamed: M401.4 (PWM), R404.2
unnamed: R204.1, R205.1, TH201.1

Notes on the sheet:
SPI1
UART0
UART1

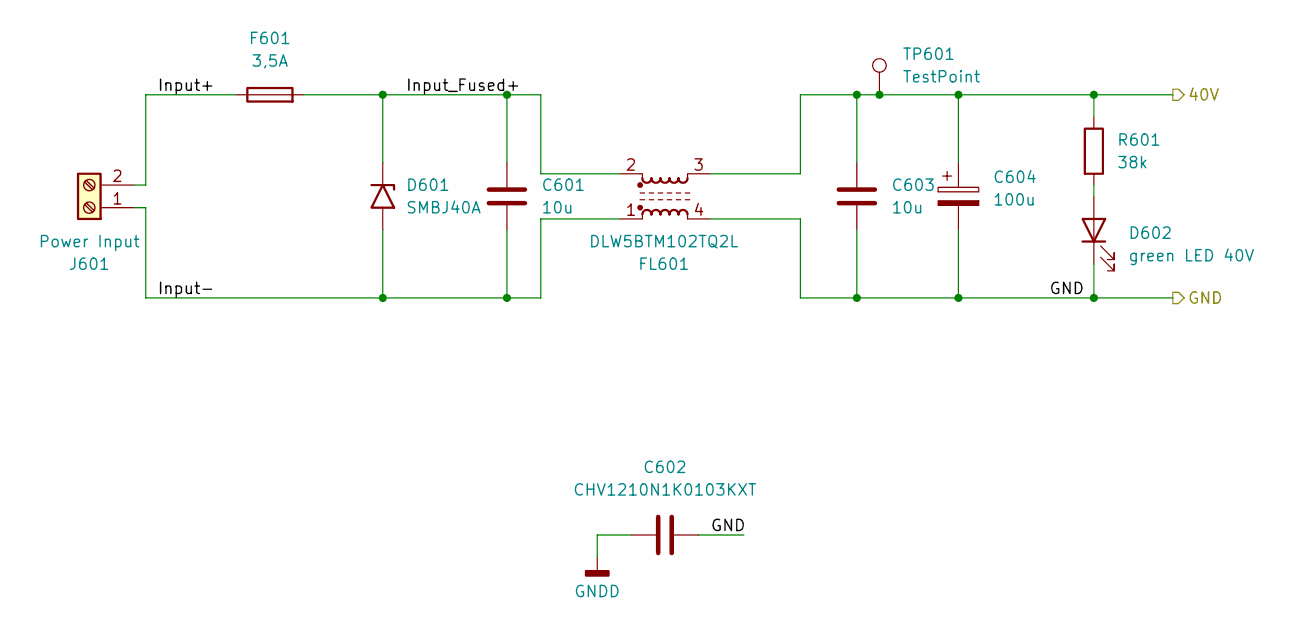
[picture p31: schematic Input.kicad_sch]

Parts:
C601, C603: 10u; C_1206_3216Metric
C602: CHV1210N1K0103KXT; C_1210_3225Metric
C604: 100u; CP_Elec_8x10.5
D601: SMBJ40A; D_SMB
D602: green LED 40V; LED_0603_1608Metric
F601: 3,5A; Fuse_1206_3216Metric
FL601: DLW5BTM102TQ2L; L_CommonModeChoke_Murata_DLW5BTMxxxSQ2x_5x5mm
J601: Power Input; PhoenixContact_MCV_1,5_2-G-3.81_1x02_P3.81mm_Vertical
R601: 38k; R_0603_1608Metric
TP601: TestPoint; SMD Test Point PCWCTE

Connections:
+40VCh1: C603.1, C604.1, FL601.3, R601.1, TP601.1 (1_1); also elsewhere on the board
/Ch1Power/Input/Input+: F601.1, J601.2
/Ch1Power/Input/Input-: C601.2, D601.2 (A2), FL601.1, J601.1
/Ch1Power/Input/Input_Fused+: C601.1, D601.1 (A1), F601.2, FL601.2
GNDD: C602.1; also elsewhere on the board
GND_Ch1: C602.2, C603.2, C604.2, D602.1 (K), FL601.4; also elsewhere on the board
unnamed: D602.2 (A), R601.2

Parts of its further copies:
C120, C135: 10u; C_1206_3216Metric
C125: CHV1210N1K0103KXT; C_1210_3225Metric
C138: 100u; CP_Elec_8x10.5
D101: SMBJ40A; D_SMB
D104: green LED 40V; LED_0603_1608Metric
F101: 3,5A; Fuse_1206_3216Metric
FL101: DLW5BTM102TQ2L; L_CommonModeChoke_Murata_DLW5BTMxxxSQ2x_5x5mm
J101: Power Input; PhoenixContact_MCV_1,5_2-G-3.81_1x02_P3.81mm_Vertical
R134: 38k; R_0603_1608Metric
TP108: TestPoint; SMD Test Point PCWCTE

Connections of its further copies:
+40VCh2: C135.1, C138.1, FL101.3, R134.1, TP108.1 (1_1); also elsewhere on the board
/Ch1Power1/Input/Input+: F101.1, J101.2
/Ch1Power1/Input/Input-: C120.2, D101.2 (A2), FL101.1, J101.1
/Ch1Power1/Input/Input_Fused+: C120.1, D101.1 (A1), F101.2, FL101.2
GNDD: C125.1; also elsewhere on the board
GND_Ch2: C125.2, C135.2, C138.2, D104.1 (K), FL101.4; also elsewhere on the board
unnamed: D104.2 (A), R134.2

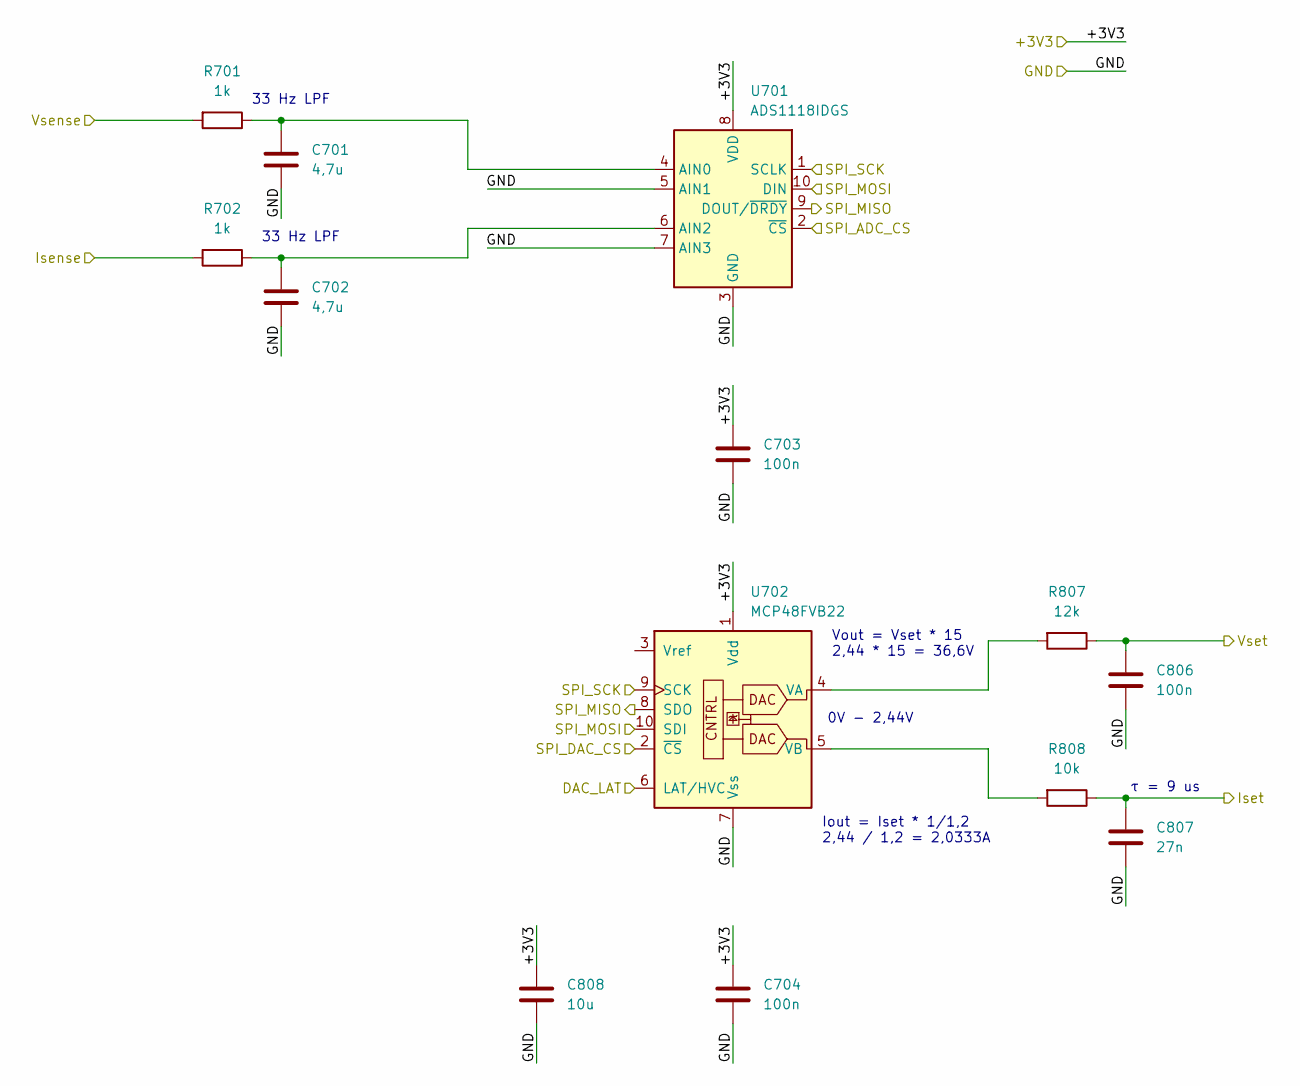
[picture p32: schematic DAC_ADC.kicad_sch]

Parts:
C701, C702: 4,7u; C_0603_1608Metric
C703, C704, C806: 100n; C_0603_1608Metric
C807: 27n; C_0603_1608Metric
C808: 10u; C_0805_2012Metric
R701, R702: 1k; R_0603_1608Metric
R807: 12k; R_0603_1608Metric
R808: 10k; R_0603_1608Metric
U701: ADS1118IDGS; TSSOP-10_3x3mm_P0.5mm
U702: MCP48FVB22; MSOP-10_3x3mm_P0.5mm

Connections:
+3V3Ch1: C703.1, C704.1, C808.1, U701.8 (VDD), U702.1 (Vdd); also elsewhere on the board
/Ch1Power/DAC_ADC/DAC_LAT: U702.6 (LAT/HVC); also elsewhere on the board
/Ch1Power/DAC_ADC/Isense: R702.2; also elsewhere on the board
/Ch1Power/DAC_ADC/Iset: C807.1, R808.1; also elsewhere on the board
/Ch1Power/DAC_ADC/SPI_ADC_CS: U701.2 (~CS); also elsewhere on the board
/Ch1Power/DAC_ADC/SPI_DAC_CS: U702.2 (~CS); also elsewhere on the board
/Ch1Power/DAC_ADC/SPI_MISO: U701.9 (DOUT/~DRDY), U702.8 (SDO); also elsewhere on the board
/Ch1Power/DAC_ADC/SPI_MOSI: U701.10 (DIN), U702.10 (SDI); also elsewhere on the board
/Ch1Power/DAC_ADC/SPI_SCK: U701.1 (SCLK), U702.9 (SCK); also elsewhere on the board
/Ch1Power/DAC_ADC/Vsense: R701.2; also elsewhere on the board
/Ch1Power/DAC_ADC/Vset: C806.1, R807.1; also elsewhere on the board
GND_Ch1: C701.2, C702.2, C703.2, C704.2, C806.2, C807.2, C808.2, U701.3 (GND), U701.5 (AIN1), U701.7 (AIN3), U702.7 (Vss); also elsewhere on the board
unnamed: C701.1, R701.1, U701.4 (AIN0)
unnamed: C702.1, R702.1, U701.6 (AIN2)
unnamed: R807.2, U702.4 (VA)
unnamed: R808.2, U702.5 (VB)

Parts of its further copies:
C113, C114: 4,7u; C_0603_1608Metric
C126, C128, C1301: 100n; C_0603_1608Metric
C1302: 27n; C_0603_1608Metric
C1303: 10u; C_0805_2012Metric
R104, R105: 1k; R_0603_1608Metric
R1301: 12k; R_0603_1608Metric
R1302: 10k; R_0603_1608Metric
U107: ADS1118IDGS; TSSOP-10_3x3mm_P0.5mm
U108: MCP48FVB22; MSOP-10_3x3mm_P0.5mm

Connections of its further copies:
+3V3Ch2: C126.1, C128.1, C1303.1, U107.8 (VDD), U108.1 (Vdd); also elsewhere on the board
/Ch1Power1/DAC_ADC/DAC_LAT: U108.6 (LAT/HVC); also elsewhere on the board
/Ch1Power1/DAC_ADC/Isense: R105.2; also elsewhere on the board
/Ch1Power1/DAC_ADC/Iset: C1302.1, R1302.1; also elsewhere on the board
/Ch1Power1/DAC_ADC/SPI_ADC_CS: U107.2 (~CS); also elsewhere on the board
/Ch1Power1/DAC_ADC/SPI_DAC_CS: U108.2 (~CS); also elsewhere on the board
/Ch1Power1/DAC_ADC/SPI_MISO: U107.9 (DOUT/~DRDY), U108.8 (SDO); also elsewhere on the board
/Ch1Power1/DAC_ADC/SPI_MOSI: U107.10 (DIN), U108.10 (SDI); also elsewhere on the board
/Ch1Power1/DAC_ADC/SPI_SCK: U107.1 (SCLK), U108.9 (SCK); also elsewhere on the board
/Ch1Power1/DAC_ADC/Vsense: R104.2; also elsewhere on the board
/Ch1Power1/DAC_ADC/Vset: C1301.1, R1301.1; also elsewhere on the board
GND_Ch2: C113.2, C114.2, C126.2, C128.2, C1301.2, C1302.2, C1303.2, U107.3 (GND), U107.5 (AIN1), U107.7 (AIN3), U108.7 (Vss); also elsewhere on the board
unnamed: C113.1, R104.1, U107.4 (AIN0)
unnamed: C114.1, R105.1, U107.6 (AIN2)
unnamed: R1301.2, U108.4 (VA)
unnamed: R1302.2, U108.5 (VB)

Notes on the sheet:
0V - 2,44V
τ = 9 us
33 Hz LPF
Iout = Iset * 1/1,2 2,44 / 1,2 = 2,0333A
Vout = Vset * 15 2,44 * 15 = 36,6V

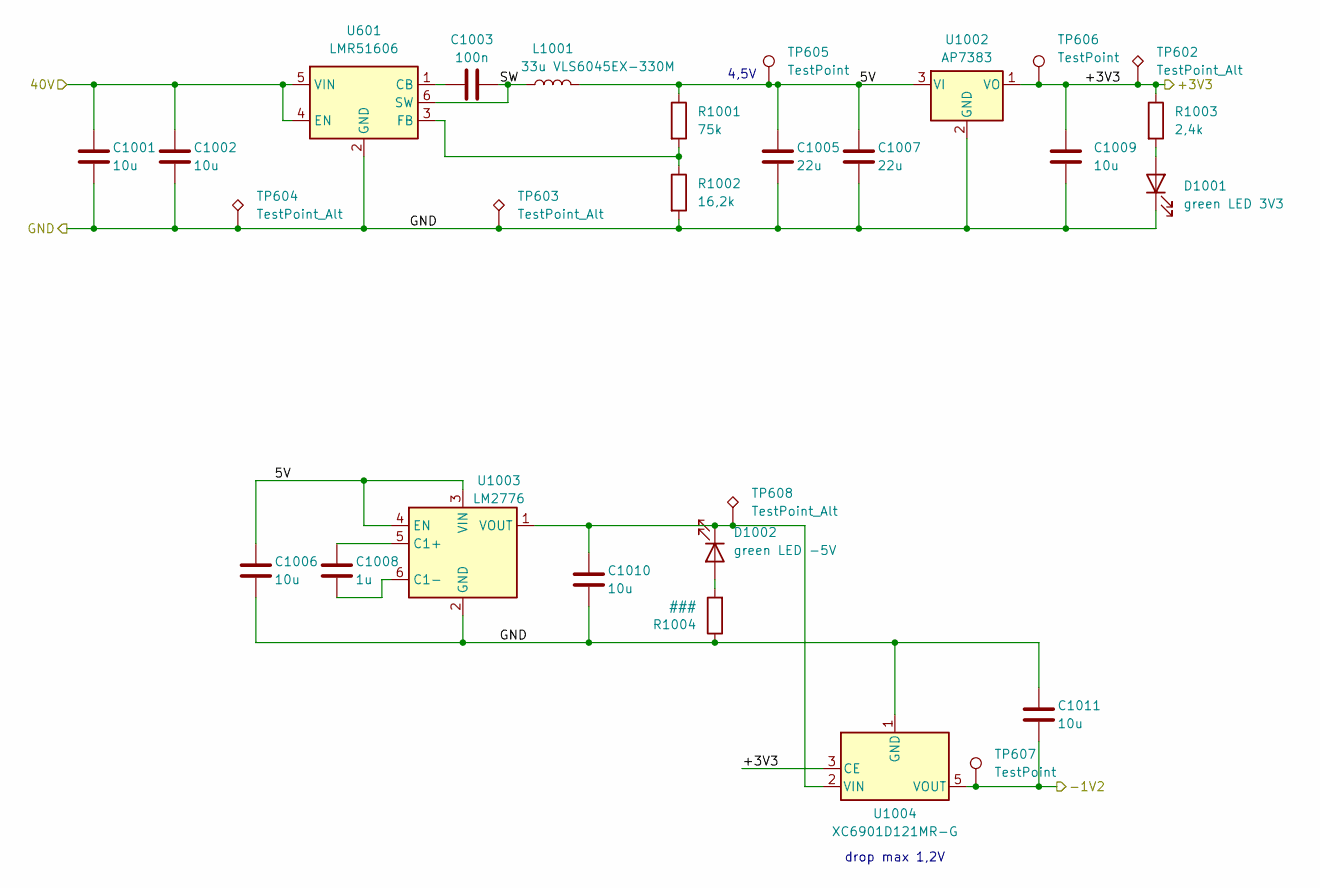
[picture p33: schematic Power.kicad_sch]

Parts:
C1001, C1002: 10u; C_1206_3216Metric
C1003: 100n; C_0603_1608Metric
C1005, C1007: 22u; C_0805_2012Metric
C1006, C1009, C1010, C1011: 10u; C_0805_2012Metric
C1008: 1u; C_0805_2012Metric
D1001: green LED 3V3; LED_0603_1608Metric
D1002: green LED -5V; LED_0603_1608Metric
L1001: 33u VLS6045EX-330M; L_TDK_VLS6045EX_VLS6045AF
R1001: 75k; R_0603_1608Metric
R1002: 16,2k; R_0603_1608Metric
R1003: 2,4k; R_0603_1608Metric
R1004: ###; R_0603_1608Metric
TP602, TP603, TP604: TestPoint_Alt; TestPoint_Keystone_5005-5009_Compact
TP605, TP606, TP607: TestPoint; SMD Test Point PCWCTE
TP608: TestPoint_Alt; TestPoint_Pad_D1.0mm
U601: LMR51606; SOT-23-6
U1002: AP7383; SOT-89-3
U1003: LM2776; SOT-23-6
U1004: XC6901D121MR-G; SC-74A-5_1.55x2.9mm_P0.95mm

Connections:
+3V3Ch1: C1009.1, R1003.1, TP602.1 (1_1), TP606.1 (1_1), U1002.1 (VO), U1004.3 (CE); also elsewhere on the board
+40VCh1: C1001.1, C1002.1, U601.4 (EN), U601.5 (VIN); also elsewhere on the board
-1V2Ch1: C1011.2, TP607.1 (1_1), U1004.5 (VOUT); also elsewhere on the board
/Ch1Power/Power/5V: C1005.1, C1006.1, C1007.1, L1001.2, R1001.1, TP605.1 (1_1), U1002.3 (VI), U1003.3 (VIN), U1003.4 (EN)
/Ch1Power/Power/SW: C1003.2, L1001.1, U601.6 (SW)
GND_Ch1: C1001.2, C1002.2, C1005.2, C1006.2, C1007.2, C1009.2, C1010.2, C1011.1, D1001.1 (K), R1002.2, R1004.1, TP603.1 (1_1), TP604.1 (1_1), U601.2 (GND), U1002.2 (GND), U1003.2 (GND), U1004.1 (GND); also elsewhere on the board
unnamed: D1001.2 (A), R1003.2
unnamed: D1002.2 (A), R1004.2
unnamed: C1010.1, D1002.1 (K), TP608.1 (1_1), U1003.1 (VOUT), U1004.2 (VIN)
unnamed: C1003.1, U601.1 (CB)
unnamed: R1001.2, R1002.1, U601.3 (FB)
unnamed: C1008.1, U1003.5 (C1+)
unnamed: C1008.2, U1003.6 (C1-)

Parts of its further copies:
C105, C107: 10u; C_1206_3216Metric
C115: 100n; C_0603_1608Metric
C124, C131: 22u; C_0805_2012Metric
C127, C139, C142, C146: 10u; C_0805_2012Metric
C133: 1u; C_0805_2012Metric
D105: green LED 3V3; LED_0603_1608Metric
D106: green LED -5V; LED_0603_1608Metric
L101: 33u VLS6045EX-330M; L_TDK_VLS6045EX_VLS6045AF
R114: 75k; R_0603_1608Metric
R115: 16,2k; R_0603_1608Metric
R136: 2,4k; R_0603_1608Metric
R139: ###; R_0603_1608Metric
TP1501, TP1502, TP1507: TestPoint_Alt; TestPoint_Keystone_5005-5009_Compact
TP1503, TP1504, TP1505: TestPoint; SMD Test Point PCWCTE
TP1506: TestPoint_Alt; TestPoint_Pad_D1.0mm
U109: AP7383; SOT-89-3
U110: LM2776; SOT-23-6
U111: XC6901D121MR-G; SC-74A-5_1.55x2.9mm_P0.95mm
U1501: LMR51606; SOT-23-6

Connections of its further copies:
+3V3Ch2: C139.1, R136.1, TP1504.1 (1_1), TP1507.1 (1_1), U109.1 (VO), U111.3 (CE); also elsewhere on the board
+40VCh2: C105.1, C107.1, U1501.4 (EN), U1501.5 (VIN); also elsewhere on the board
-1V2Ch2: C146.2, TP1505.1 (1_1), U111.5 (VOUT); also elsewhere on the board
/Ch1Power1/Power/5V: C124.1, C127.1, C131.1, L101.2, R114.1, TP1503.1 (1_1), U109.3 (VI), U110.3 (VIN), U110.4 (EN)
/Ch1Power1/Power/SW: C115.2, L101.1, U1501.6 (SW)
GND_Ch2: C105.2, C107.2, C124.2, C127.2, C131.2, C139.2, C142.2, C146.1, D105.1 (K), R115.2, R139.1, TP1501.1 (1_1), TP1502.1 (1_1), U109.2 (GND), U110.2 (GND), U111.1 (GND), U1501.2 (GND); also elsewhere on the board
unnamed: D105.2 (A), R136.2
unnamed: D106.2 (A), R139.2
unnamed: C142.1, D106.1 (K), TP1506.1 (1_1), U110.1 (VOUT), U111.2 (VIN)
unnamed: C133.1, U110.5 (C1+)
unnamed: C133.2, U110.6 (C1-)
unnamed: C115.1, U1501.1 (CB)
unnamed: R114.2, R115.1, U1501.3 (FB)

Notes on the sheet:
4,5V
drop max 1,2V

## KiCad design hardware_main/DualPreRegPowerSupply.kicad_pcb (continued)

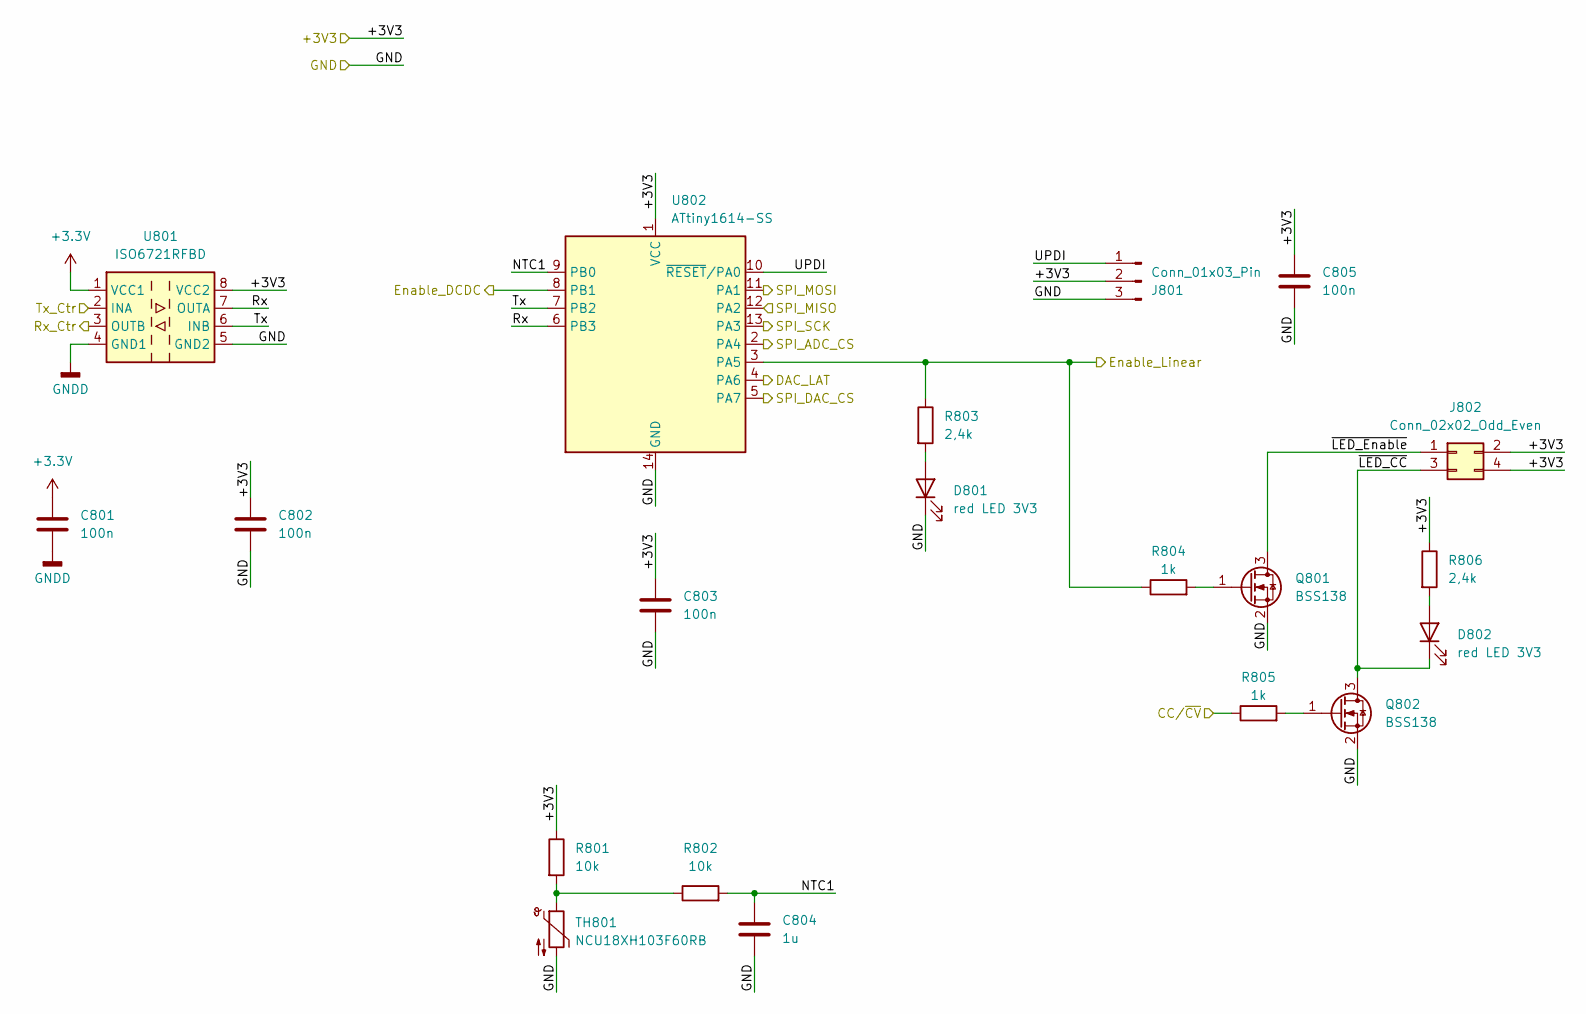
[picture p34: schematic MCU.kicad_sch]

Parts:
C801, C802, C803, C805: 100n; C_0603_1608Metric
C804: 1u; C_0603_1608Metric
D801, D802: red LED 3V3; LED_0603_1608Metric
J801: Conn_01x03_Pin; JST_SH_BM03B-SRSS-TB_1x03-1MP_P1.00mm_Vertical
J802: Conn_02x02_Odd_Even; PinHeader_2x02_P2.54mm_Horizontal
Q801, Q802: BSS138; SOT-23
R801, R802: 10k; R_0603_1608Metric
R803, R806: 2,4k; R_0603_1608Metric
R804, R805: 1k; R_0603_1608Metric
TH801: NCU18XH103F60RB; R_0603_1608Metric
U801: ISO6721RFBD; SOIC-8_3.9x4.9mm_P1.27mm
U802: ATtiny1614-SS; SOIC-14_3.9x8.7mm_P1.27mm

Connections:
+3.3V: C801.1, U801.1 (VCC1); also elsewhere on the board
+3V3Ch1: C802.1, C803.1, C805.1, J801.2, J802.2, J802.4, R801.1, R806.1, U801.8 (VCC2), U802.1 (VCC); also elsewhere on the board
/Ch1Power/DAC_ADC/DAC_LAT: U802.4 (PA6); also elsewhere on the board
/Ch1Power/DAC_ADC/SPI_ADC_CS: U802.2 (PA4); also elsewhere on the board
/Ch1Power/DAC_ADC/SPI_DAC_CS: U802.5 (PA7); also elsewhere on the board
/Ch1Power/DAC_ADC/SPI_MISO: U802.12 (PA2); also elsewhere on the board
/Ch1Power/DAC_ADC/SPI_MOSI: U802.11 (PA1); also elsewhere on the board
/Ch1Power/DAC_ADC/SPI_SCK: U802.13 (PA3); also elsewhere on the board
/Ch1Power/DCDCTracking/Enable: U802.8 (PB1); also elsewhere on the board
/Ch1Power/Linear_PostReg/CC/~CV: R805.1; also elsewhere on the board
/Ch1Power/Linear_PostReg/OE: R803.1, R804.1, U802.3 (PA5); also elsewhere on the board
/Ch1Power/MCU/NTC1: C804.1, R802.2, U802.9 (PB0)
/Ch1Power/MCU/Rx: U801.7 (OUTA), U802.6 (PB3)
/Ch1Power/MCU/Tx: U801.6 (INB), U802.7 (PB2)
/Ch1Power/MCU/UPDI: J801.1, U802.10 (~RESET/PA0)
/Ch1Power/MCU/~LED_CC: D802.1 (K), J802.3, Q802.3 (D)
/Ch1Power/MCU/~LED_Enable: J802.1, Q801.3 (D)
/Ch1Power/Rx_Ctr: U801.3 (OUTB); also elsewhere on the board
/Ch1Power/Tx_Ctr: U801.2 (INA); also elsewhere on the board
GNDD: C801.2, U801.4 (GND1); also elsewhere on the board
GND_Ch1: C802.2, C803.2, C804.2, C805.2, D801.1 (K), J801.3, Q801.2 (S), Q802.2 (S), TH801.2, U801.5 (GND2), U802.14 (GND); also elsewhere on the board
unnamed: D801.2 (A), R803.2
unnamed: D802.2 (A), R806.2
unnamed: Q801.1 (G), R804.2
unnamed: Q802.1 (G), R805.2
unnamed: R801.2, R802.1, TH801.1

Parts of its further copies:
C106, C109, C117, C144: 100n; C_0603_1608Metric
C122: 1u; C_0603_1608Metric
D103, D107: red LED 3V3; LED_0603_1608Metric
J102: Conn_01x03_Pin; JST_SH_BM03B-SRSS-TB_1x03-1MP_P1.00mm_Vertical
J103: Conn_02x02_Odd_Even; PinHeader_2x02_P2.54mm_Horizontal
Q105, Q106: BSS138; SOT-23
R109, R113: 10k; R_0603_1608Metric
R124, R140: 2,4k; R_0603_1608Metric
R135, R137: 1k; R_0603_1608Metric
TH101: NCU18XH103F60RB; R_0603_1608Metric
U102: ISO6721RFBD; SOIC-8_3.9x4.9mm_P1.27mm
U106: ATtiny1614-SS; SOIC-14_3.9x8.7mm_P1.27mm

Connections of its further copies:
+3.3V: C106.1, U102.1 (VCC1); also elsewhere on the board
+3V3Ch2: C109.1, C117.1, C144.1, J102.2, J103.2, J103.4, R109.1, R140.1, U102.8 (VCC2), U106.1 (VCC); also elsewhere on the board
/Ch1Power1/DAC_ADC/DAC_LAT: U106.4 (PA6); also elsewhere on the board
/Ch1Power1/DAC_ADC/SPI_ADC_CS: U106.2 (PA4); also elsewhere on the board
/Ch1Power1/DAC_ADC/SPI_DAC_CS: U106.5 (PA7); also elsewhere on the board
/Ch1Power1/DAC_ADC/SPI_MISO: U106.12 (PA2); also elsewhere on the board
/Ch1Power1/DAC_ADC/SPI_MOSI: U106.11 (PA1); also elsewhere on the board
/Ch1Power1/DAC_ADC/SPI_SCK: U106.13 (PA3); also elsewhere on the board
/Ch1Power1/DCDCTracking/Enable: U106.8 (PB1); also elsewhere on the board
/Ch1Power1/Linear_PostReg/CC/~CV: R137.1; also elsewhere on the board
/Ch1Power1/Linear_PostReg/OE: R124.1, R135.1, U106.3 (PA5); also elsewhere on the board
/Ch1Power1/MCU/NTC1: C122.1, R113.2, U106.9 (PB0)
/Ch1Power1/MCU/Rx: U102.7 (OUTA), U106.6 (PB3)
/Ch1Power1/MCU/Tx: U102.6 (INB), U106.7 (PB2)
/Ch1Power1/MCU/UPDI: J102.1, U106.10 (~RESET/PA0)
/Ch1Power1/MCU/~LED_CC: D107.1 (K), J103.3, Q106.3 (D)
/Ch1Power1/MCU/~LED_Enable: J103.1, Q105.3 (D)
/Ch1Power1/Rx_Ctr: U102.3 (OUTB); also elsewhere on the board
/Ch1Power1/Tx_Ctr: U102.2 (INA); also elsewhere on the board
GNDD: C106.2, U102.4 (GND1); also elsewhere on the board
GND_Ch2: C109.2, C117.2, C122.2, C144.2, D103.1 (K), J102.3, Q105.2 (S), Q106.2 (S), TH101.2, U102.5 (GND2), U106.14 (GND); also elsewhere on the board
unnamed: D103.2 (A), R124.2
unnamed: D107.2 (A), R140.2
unnamed: Q105.1 (G), R135.2
unnamed: Q106.1 (G), R137.2
unnamed: R109.2, R113.1, TH101.1

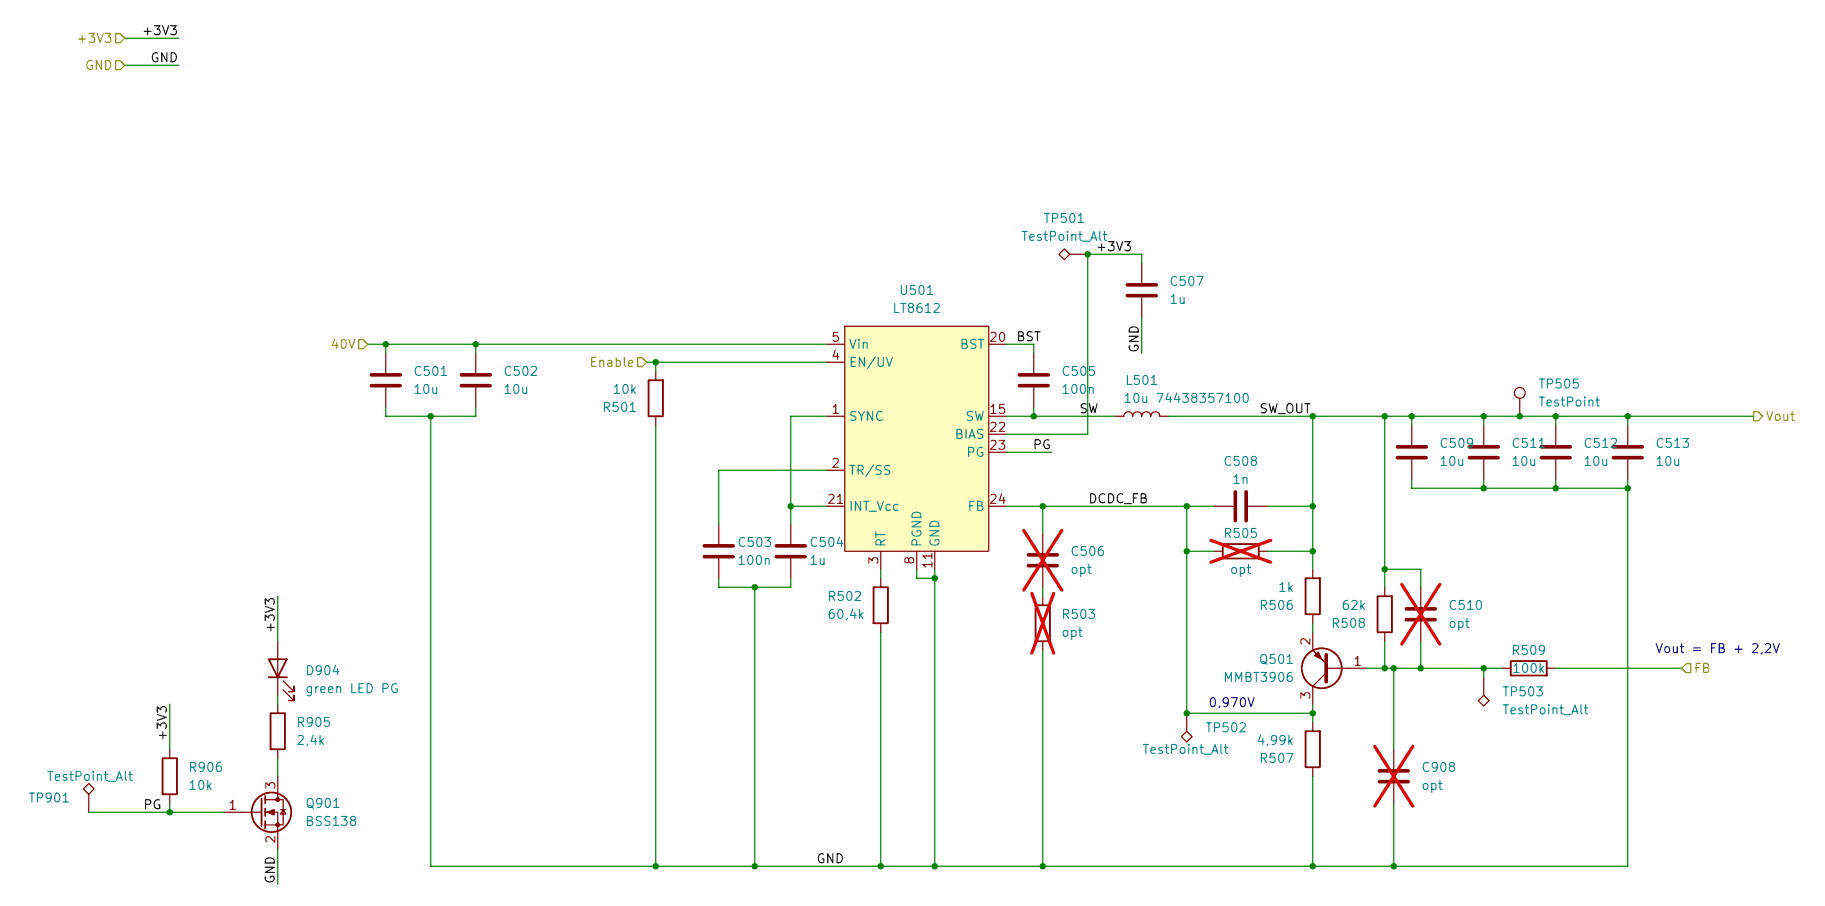
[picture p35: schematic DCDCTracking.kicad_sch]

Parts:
C501, C502, C509, C511, C512, C513: 10u; C_1206_3216Metric
C503, C505: 100n; C_0603_1608Metric
C504, C507: 1u; C_0603_1608Metric
C506, C510, C908: opt; C_0603_1608Metric; not fitted
C508: 1n; C_0603_1608Metric
D904: green LED PG; LED_0603_1608Metric
L501: 10u 74438357100; L_Wuerth_MAPI-4030
Q501: MMBT3906; SOT-23-3
Q901: BSS138; SOT-23
R501, R906: 10k; R_0603_1608Metric
R502: 60,4k; R_0603_1608Metric
R503, R505: opt; R_0603_1608Metric; not fitted
R506: 1k; R_0603_1608Metric
R507: 4,99k; R_0603_1608Metric
R508: 62k; R_0603_1608Metric
R509: 100k; R_0603_1608Metric
R905: 2,4k; R_0603_1608Metric
TP501, TP502, TP503, TP901: TestPoint_Alt; TestPoint_Pad_D1.0mm
TP505: TestPoint; SMD Test Point PCWCTE
U501: LT8612; QFN-28-1EP_3x6mm_P0.5mm_EP1.7x4.75mm_ThermalVias

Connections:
+3V3Ch1: C507.1, D904.2 (A), R906.1, TP501.1 (1_1), U501.22 (BIAS); also elsewhere on the board
+40VCh1: C501.1, C502.1, U501.5 (Vin), U501.6 (Vin), U501.7 (Vin); also elsewhere on the board
/Ch1Power/DCDCTracking/BST: C505.1, U501.20 (BST)
/Ch1Power/DCDCTracking/DCDC_FB: C506.1, C508.1, Q501.3 (C), R505.1, R507.2, TP502.1 (1_1), U501.24 (FB)
/Ch1Power/DCDCTracking/Enable: R501.2, U501.4 (EN/UV); also elsewhere on the board
/Ch1Power/DCDCTracking/PG: Q901.1 (G), R906.2, TP901.1 (1_1), U501.23 (PG)
/Ch1Power/DCDCTracking/SW: C505.2, L501.1, U501.15 (SW), U501.16 (SW), U501.17 (SW), U501.18 (SW), U501.19 (SW)
/Ch1Power/DCDCTracking/SW_OUT: C508.2, C509.1, C510.1, C511.1, C512.1, C513.1, L501.2, R505.2, R506.2, R508.2, TP505.1 (1_1); also elsewhere on the board
/Ch1Power/Linear_PostReg/OUT+: R509.2; also elsewhere on the board
GND_Ch1: C501.2, C502.2, C503.2, C504.2, C507.2, C509.2, C511.2, C512.2, C513.2, C908.2, Q901.2 (S), R501.1, R502.2, R503.2, R507.1, U501.8 (PGND), U501.9 (PGND), U501.10 (PGND), U501.11 (GND), U501.12 (GND), U501.13 (GND), U501.14 (GND), U501.29 (GND); also elsewhere on the board
unnamed: C506.2, R503.1
unnamed: D904.1 (K), R905.1
unnamed: C510.2, C908.1, Q501.1 (B), R508.1, R509.1, TP503.1 (1_1)
unnamed: Q501.2 (E), R506.1
unnamed: Q901.3 (D), R905.2
unnamed: C504.1, U501.1 (SYNC), U501.21 (INT_Vcc)
unnamed: R502.1, U501.3 (RT)
unnamed: C503.1, U501.2 (TR/SS)

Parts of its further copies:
C101, C102, C136, C140, C141, C143: 10u; C_1206_3216Metric
C108, C118: 100n; C_0603_1608Metric
C110, C123: 1u; C_0603_1608Metric
C119, C137, C1401: opt; C_0603_1608Metric; not fitted
C129: 1n; C_0603_1608Metric
D1401: green LED PG; LED_0603_1608Metric
L102: 10u 74438357100; L_Wuerth_MAPI-4030
Q101: MMBT3906; SOT-23-3
Q1401: BSS138; SOT-23
R101, R1402: 10k; R_0603_1608Metric
R108: 60,4k; R_0603_1608Metric
R110, R122: opt; R_0603_1608Metric; not fitted
R125: 1k; R_0603_1608Metric
R126: 4,99k; R_0603_1608Metric
R130: 62k; R_0603_1608Metric
R133: 100k; R_0603_1608Metric
R1401: 2,4k; R_0603_1608Metric
TP106, TP107, TP110, TP1401: TestPoint_Alt; TestPoint_Pad_D1.0mm
TP112: TestPoint; SMD Test Point PCWCTE
U104: LT8612; QFN-28-1EP_3x6mm_P0.5mm_EP1.7x4.75mm_ThermalVias

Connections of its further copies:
+3V3Ch2: C123.1, D1401.2 (A), R1402.1, TP106.1 (1_1), U104.22 (BIAS); also elsewhere on the board
+40VCh2: C101.1, C102.1, U104.5 (Vin), U104.6 (Vin), U104.7 (Vin); also elsewhere on the board
/Ch1Power1/DCDCTracking/BST: C118.1, U104.20 (BST)
/Ch1Power1/DCDCTracking/DCDC_FB: C119.1, C129.1, Q101.3 (C), R122.1, R126.2, TP107.1 (1_1), U104.24 (FB)
/Ch1Power1/DCDCTracking/Enable: R101.2, U104.4 (EN/UV); also elsewhere on the board
/Ch1Power1/DCDCTracking/PG: Q1401.1 (G), R1402.2, TP1401.1 (1_1), U104.23 (PG)
/Ch1Power1/DCDCTracking/SW: C118.2, L102.1, U104.15 (SW), U104.16 (SW), U104.17 (SW), U104.18 (SW), U104.19 (SW)
/Ch1Power1/DCDCTracking/SW_OUT: C129.2, C136.1, C137.1, C140.1, C141.1, C143.1, L102.2, R122.2, R125.2, R130.2, TP112.1 (1_1); also elsewhere on the board
/Ch1Power1/Linear_PostReg/OUT+: R133.2; also elsewhere on the board
GND_Ch2: C101.2, C102.2, C108.2, C110.2, C123.2, C136.2, C140.2, C141.2, C143.2, C1401.2, Q1401.2 (S), R101.1, R108.2, R110.2, R126.1, U104.8 (PGND), U104.9 (PGND), U104.10 (PGND), U104.11 (GND), U104.12 (GND), U104.13 (GND), U104.14 (GND), U104.29 (GND); also elsewhere on the board
unnamed: C119.2, R110.1
unnamed: D1401.1 (K), R1401.1
unnamed: C137.2, C1401.1, Q101.1 (B), R130.1, R133.1, TP110.1 (1_1)
unnamed: Q101.2 (E), R125.1
unnamed: Q1401.3 (D), R1401.2
unnamed: C110.1, U104.1 (SYNC), U104.21 (INT_Vcc)
unnamed: R108.1, U104.3 (RT)
unnamed: C108.1, U104.2 (TR/SS)

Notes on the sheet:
Vout = FB + 2,2V
0,970V

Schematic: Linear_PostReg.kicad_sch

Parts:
C301, C302, C307, C310, C1015: 100n; C_0603_1608Metric
C303: 47n; C_0603_1608Metric
C304: 27n; C_0603_1608Metric
C305, C306, C308: 10p; C_0603_1608Metric; not fitted
C309: 10u; C_1206_3216Metric
C1004: 100p; C_0603_1608Metric; not fitted
C1012, C1013: 2,2u; C_0603_1608Metric
C1014: 22p; C_0603_1608Metric
D1003, D1004, D1006, D1007, D1008: 1N4148WS; D_SOD-323
D1005: MM3Z4V7T1G; D_SOD-323; not fitted
F301: 3A; Fuse_1206_3216Metric
Q301, Q304: BCP56; SOT-223
Q302: BSS138; SOT-23-3
Q303: TIP125; TO-220-3_Horizontal_TabUp
R301, R302, R310: 10k; R_0603_1608Metric
R303: 18k; R_0603_1608Metric
R304, R311: 0; R_0603_1608Metric
R305: 1,2k; R_0603_1608Metric
R306, R309: 2,2k 0,1%; R_0603_1608Metric
R307: 3,3k; R_0603_1608Metric
R308: 1k; R_0603_1608Metric
R312: 220; R_0603_1608Metric
R313, R314: 33k 0,1%; R_0603_1608Metric
R315: 150; R_1206_3216Metric
R316: 11k 0,1%; R_0603_1608Metric
R317: 1k 0,1%; R_0603_1608Metric
R318: 100m; R_2512_6332Metric
R319: 200m; R_1206_3216Metric
R320: 47; R_0603_1608Metric
TP301: Vsense; TestPoint_Pad_D1.0mm
TP302: CV_loop; TestPoint_Pad_D1.0mm
TP303: CC_loop; TestPoint_Pad_D1.0mm
TP304: CC/CV; TestPoint_Pad_D1.0mm
TP305: Isense; TestPoint_Pad_D1.0mm
U301: TLV4387PWR; TSSOP-14_4.4x5mm_P0.65mm
U302: LMV331; SOT-353_SC-70-5

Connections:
+3V3Ch1: C301.1, C307.1, C1012.1, C1015.1, R307.1, R308.1, U301.4 (V+), U302.5 (V+); also elsewhere on the board
-1V2Ch1: C302.2, C307.2, C310.2, C1013.2, R320.2, U301.11 (V-), U302.2 (V-); also elsewhere on the board
/Ch1Power/DAC_ADC/Isense: C308.1, R302.1, R316.1, TP305.1 (1_1), U301.8; also elsewhere on the board
/Ch1Power/DAC_ADC/Iset: U301.5 (+); also elsewhere on the board
/Ch1Power/DAC_ADC/Vsense: C305.1, R301.1, R306.1, TP301.1 (1_1), U301.14; also elsewhere on the board
/Ch1Power/DAC_ADC/Vset: U301.3 (+); also elsewhere on the board
/Ch1Power/Linear_PostReg/Base: Q301.1 (B), R311.2
/Ch1Power/Linear_PostReg/Base_drive: D1005.2 (A), Q301.2 (C), Q301.4 (C), Q303.1 (B)
/Ch1Power/Linear_PostReg/CC_loop: C1004.2, D1003.2 (A), D1007.1 (K), R304.2, TP303.1 (1_1), U301.7, U302.3 (-)
/Ch1Power/Linear_PostReg/CC/CV_loop: D1007.2 (A), D1008.2 (A), R308.2, R311.1, TP304.1 (1_1)
/Ch1Power/Linear_PostReg/CC/~CV: R305.2, R307.2; also elsewhere on the board
/Ch1Power/Linear_PostReg/CV_loop: C1014.2, D1004.2 (A), D1008.1 (K), R303.2, TP302.1 (1_1), U301.1, U302.1 (+)
/Ch1Power/Linear_PostReg/OE: R310.2, R312.2; also elsewhere on the board
/Ch1Power/Linear_PostReg/OUT+: F301.2, R313.2, R319.1; also elsewhere on the board
/Ch1Power/Linear_PostReg/OUT-: C309.2, R314.2, R318.1, U301.10 (+); also elsewhere on the board
/Ch1Power/Linear_PostReg/PreReg: D1005.1 (K), Q303.3 (E); also elsewhere on the board
/Ch1Power/Linear_PostReg/preFuseOut+: D1006.2 (A), F301.1, Q303.2 (C)
GND_Ch1: C301.2, C302.1, C306.1, C310.1, C1012.2, C1013.1, C1015.2, Q302.2 (S), Q304.1 (B), R309.2, R310.1, R317.2, R318.2; also elsewhere on the board
unnamed: C303.2, R303.1
unnamed: C304.2, R304.1
unnamed: C309.1, R319.2
unnamed: C304.1, C1004.1, D1003.1 (K), R302.2, U301.6 (-)
unnamed: C303.1, C1014.1, D1004.1 (K), R301.2, U301.2 (-)
unnamed: D1006.1 (K), Q304.2 (C), Q304.4 (C)
unnamed: Q301.3 (E), R315.1
unnamed: Q302.3 (D), R315.2
unnamed: Q302.1 (G), R312.1
unnamed: Q304.3 (E), R320.1
unnamed: R305.1, U302.4
unnamed: C308.2, R316.2, R317.1, U301.9 (-)
unnamed: C306.2, R309.1, R313.1, U301.12 (+)
unnamed: C305.2, R306.2, R314.1, U301.13 (-)

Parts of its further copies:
C103, C104, C132, C147, C1205: 100n; C_0603_1608Metric
C111: 47n; C_0603_1608Metric
C112: 27n; C_0603_1608Metric
C121, C130, C134: 10p; C_0603_1608Metric; not fitted
C145: 10u; C_1206_3216Metric
C1201, C1202: 2,2u; C_0603_1608Metric
C1203: 100p; C_0603_1608Metric; not fitted
C1204: 22p; C_0603_1608Metric
D1201, D1202, D1204, D1205, D1206: 1N4148WS; D_SOD-323
D1203: MM3Z4V7T1G; D_SOD-323; not fitted
F102: 3A; Fuse_1206_3216Metric
Q102, Q107: BCP56; SOT-223
Q103: BSS138; SOT-23-3
Q104: TIP125; TO-220-3_Horizontal_TabUp
R102, R103, R120: 10k; R_0603_1608Metric
R106: 18k; R_0603_1608Metric
R107, R121: 0; R_0603_1608Metric
R112: 1,2k; R_0603_1608Metric
R116, R119: 2,2k 0,1%; R_0603_1608Metric
R117: 3,3k; R_0603_1608Metric
R118: 1k; R_0603_1608Metric
R123: 220; R_0603_1608Metric
R127, R128: 33k 0,1%; R_0603_1608Metric
R129: 150; R_1206_3216Metric
R131: 11k 0,1%; R_0603_1608Metric
R132: 1k 0,1%; R_0603_1608Metric
R138: 100m; R_2512_6332Metric
R141: 200m; R_1206_3216Metric
R142: 47; R_0603_1608Metric
TP101: Vsense; TestPoint_Pad_D1.0mm
TP102: CV_loop; TestPoint_Pad_D1.0mm
TP103: CC_loop; TestPoint_Pad_D1.0mm
TP104: CC/CV; TestPoint_Pad_D1.0mm
TP105: Isense; TestPoint_Pad_D1.0mm
U101: TLV4387PWR; TSSOP-14_4.4x5mm_P0.65mm
U105: LMV331; SOT-353_SC-70-5

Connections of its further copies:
+3V3Ch2: C103.1, C132.1, C1201.1, C1205.1, R117.1, R118.1, U101.4 (V+), U105.5 (V+); also elsewhere on the board
-1V2Ch2: C104.2, C132.2, C147.2, C1202.2, R142.2, U101.11 (V-), U105.2 (V-); also elsewhere on the board
/Ch1Power1/DAC_ADC/Isense: C134.1, R103.1, R131.1, TP105.1 (1_1), U101.8; also elsewhere on the board
/Ch1Power1/DAC_ADC/Iset: U101.5 (+); also elsewhere on the board
/Ch1Power1/DAC_ADC/Vsense: C121.1, R102.1, R116.1, TP101.1 (1_1), U101.14; also elsewhere on the board
/Ch1Power1/DAC_ADC/Vset: U101.3 (+); also elsewhere on the board
/Ch1Power1/Linear_PostReg/Base: Q102.1 (B), R121.2
/Ch1Power1/Linear_PostReg/Base_drive: D1203.2 (A), Q102.2 (C), Q102.4 (C), Q104.1 (B)
/Ch1Power1/Linear_PostReg/CC_loop: C1203.2, D1201.2 (A), D1205.1 (K), R107.2, TP103.1 (1_1), U101.7, U105.3 (-)
/Ch1Power1/Linear_PostReg/CC/CV_loop: D1205.2 (A), D1206.2 (A), R118.2, R121.1, TP104.1 (1_1)
/Ch1Power1/Linear_PostReg/CC/~CV: R112.2, R117.2; also elsewhere on the board
/Ch1Power1/Linear_PostReg/CV_loop: C1204.2, D1202.2 (A), D1206.1 (K), R106.2, TP102.1 (1_1), U101.1, U105.1 (+)
/Ch1Power1/Linear_PostReg/OE: R120.2, R123.2; also elsewhere on the board
/Ch1Power1/Linear_PostReg/OUT+: F102.2, R127.2, R141.1; also elsewhere on the board
/Ch1Power1/Linear_PostReg/OUT-: C145.2, R128.2, R138.1, U101.10 (+); also elsewhere on the board
/Ch1Power1/Linear_PostReg/PreReg: D1203.1 (K), Q104.3 (E); also elsewhere on the board
/Ch1Power1/Linear_PostReg/preFuseOut+: D1204.2 (A), F102.1, Q104.2 (C)
GND_Ch2: C103.2, C104.1, C130.1, C147.1, C1201.2, C1202.1, C1205.2, Q103.2 (S), Q107.1 (B), R119.2, R120.1, R132.2, R138.2; also elsewhere on the board
unnamed: C111.2, R106.1
unnamed: C112.2, R107.1
unnamed: C145.1, R141.2
unnamed: C112.1, C1203.1, D1201.1 (K), R103.2, U101.6 (-)
unnamed: C111.1, C1204.1, D1202.1 (K), R102.2, U101.2 (-)
unnamed: D1204.1 (K), Q107.2 (C), Q107.4 (C)
unnamed: Q102.3 (E), R129.1
unnamed: Q103.3 (D), R129.2
unnamed: Q103.1 (G), R123.1
unnamed: Q107.3 (E), R142.1
unnamed: R112.1, U105.4
unnamed: C134.2, R131.2, R132.1, U101.9 (-)
unnamed: C130.2, R119.1, R127.1, U101.12 (+)
unnamed: C121.2, R116.2, R128.1, U101.13 (-)

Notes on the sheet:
@2A 200mV 400mW
G=1/15 Vin=36V --> Vout=2,4V
beta min 1000
~12mA
PCSK2512DR100P6 0,5% 25PPM/C
G=12 Vin=200mV --> Vout=2,4V
PreReg = Vout + 2,2V
4,7V Zener

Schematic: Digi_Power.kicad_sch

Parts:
C901, C902: 10u; C_0805_2012Metric
C903: 100n; C_0603_1608Metric
C904: 100p; C_0603_1608Metric
C905, C906, C907: 22u; C_0805_2012Metric
D901: SMBJ12A; D_SMB
D902: green LED 12V; LED_0603_1608Metric
D903: green LED 3V3; LED_0603_1608Metric
F901: 3,5A; Fuse_1206_3216Metric
J901: Power Input; PhoenixContact_MCV_1,5_2-G-3.81_1x02_P3.81mm_Vertical
L901: 6,8u LBC3225T6R8MR; L_1210_3225Metric
R901, R904: ###; R_0603_1608Metric
R902: 196k; R_0603_1608Metric
R903: 62k; R_0603_1608Metric
TP306, TP307, TP308: TestPoint_Alt; TestPoint_Keystone_5005-5009_Compact
U901: AP63200WU; TSOT-23-6

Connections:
+3.3V: C904.1, C905.1, C906.1, C907.1, L901.2, R902.1, R904.1, TP307.1 (1_1); also elsewhere on the board
+12V: C901.1, C902.1, D901.1 (A1), F901.2, R901.1, TP308.1 (1_1), U901.2 (EN), U901.3 (IN); also elsewhere on the board
/Control/Digi_Power/SW: C903.2, L901.1, U901.5 (SW)
GNDD: C901.2, C902.2, C905.2, C906.2, C907.2, D901.2 (A2), D902.1 (K), D903.1 (K), J901.1, R903.2, TP306.1 (1_1), U901.4 (GND); also elsewhere on the board
unnamed: D902.2 (A), R901.2
unnamed: D903.2 (A), R904.2
unnamed: F901.1, J901.2
unnamed: C903.1, U901.6 (BST)
unnamed: C904.2, R902.2, R903.1, U901.1 (FB)

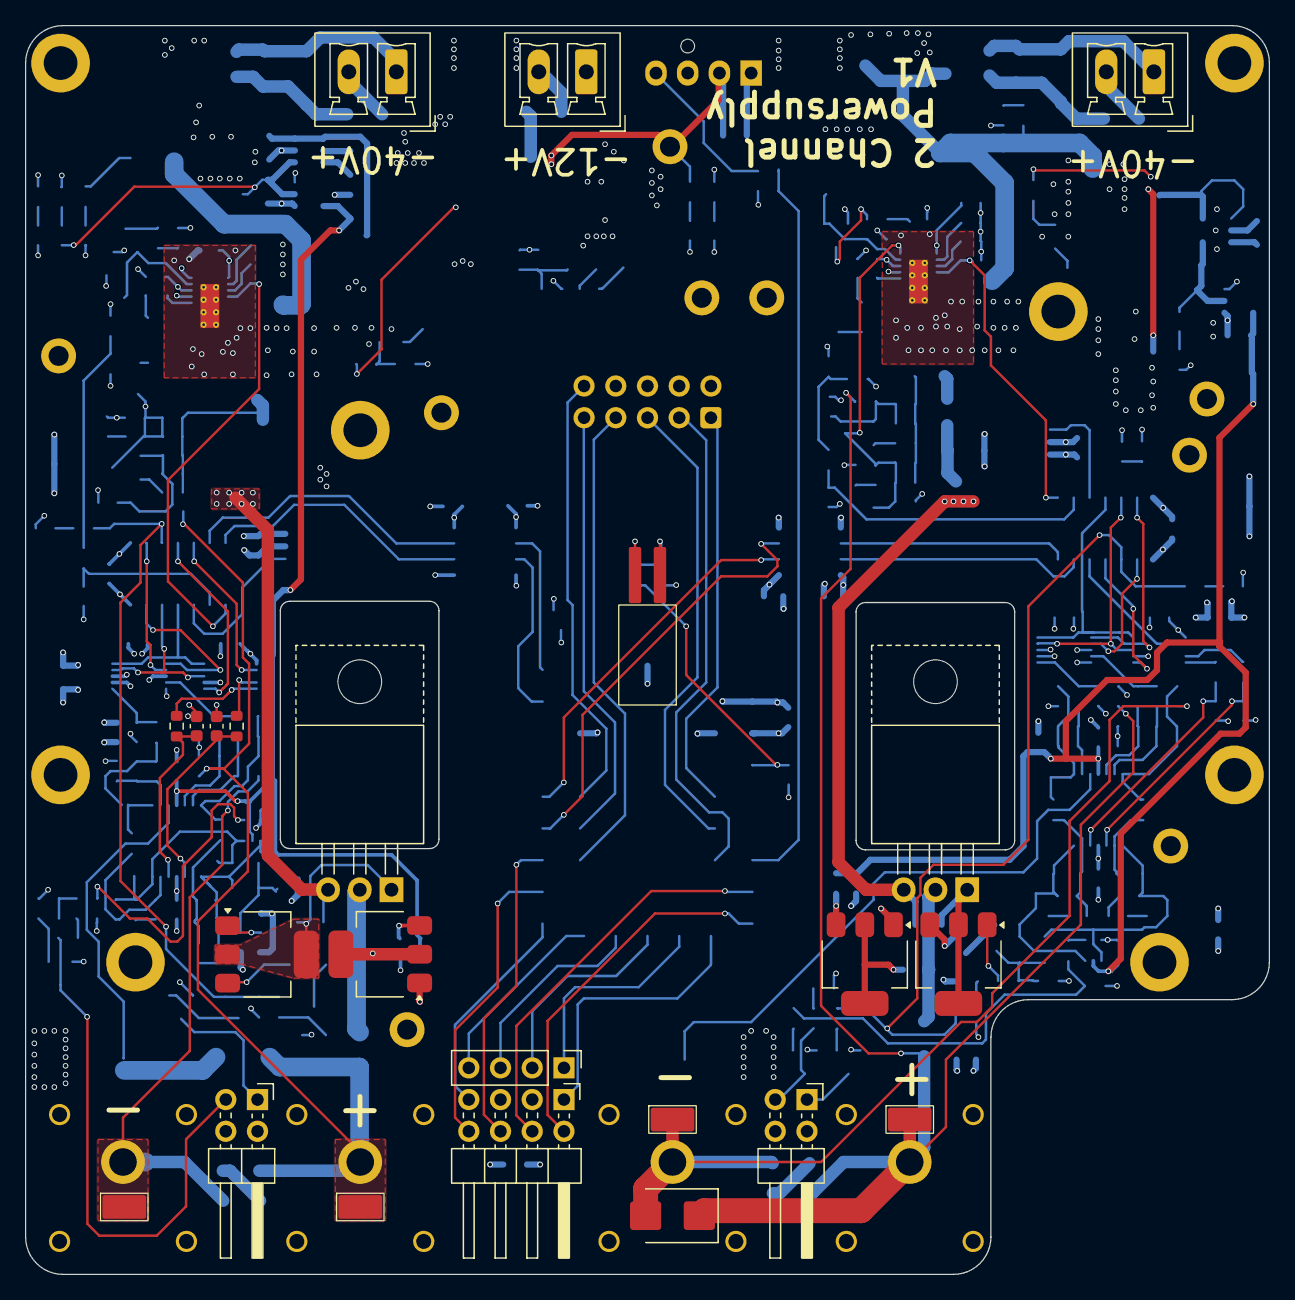
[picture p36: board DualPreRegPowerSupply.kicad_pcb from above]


Board: 4 copper layers, 99.6 x 100.0 mm, 379 parts (350 on the bottom side), 195 nets.

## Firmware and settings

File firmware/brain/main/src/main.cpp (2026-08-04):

#include <Arduino.h>
#include <EEPROM.h>
#include <SSD1322.h>
#include <Wire.h>
#include <math.h>
#include <stddef.h>   // offsetof
#include <stdio.h>
#include <string.h>

#include "channel_link.h"   // UART link to the two ATtiny1614 channel boards
#include "protocol.h"       // ST_* / FLAG_* telemetry decode constants
#include "brain_api.h"      // hooks the SCPI layer calls into this app state
#include "netcfg.h"         // W5500 Ethernet + SCPI TCP transport
#include "scpi.h"           // SCPI-1999 remote-control parser

// USB CDC console doubles as a SCPI transport, so the panel's own debug chatter
// is compiled out by default (it would otherwise corrupt SCPI responses). Flip
// to 1 only for bring-up on a dedicated serial monitor.
#define BRAIN_SERIAL_DEBUG 0

// Hardware watchdog period. Armed at the end of setup() and fed at the end of
// every loop(); see the comment there for why it exists and why this value.
#define BRAIN_WDT_TIMEOUT_MS 4000

// ── Front-panel OLED wiring (SSD1322 256x64) on the RP2350-Tiny brain ──────────
//   RES  -> GPIO9     reset          (manual GPIO)
//   SCK  -> GPIO10    SPI1 SCK
//   MOSI -> GPIO11    SPI1 TX
//   DC   -> GPIO12    data/command   (manual GPIO)
//   CS   -> GPIO13    chip select    (manual GPIO)
// GPIO10/GPIO11 are the SPI1 clock/data functions, so the driver uses SPI1.
#define PIN_RES  9
#define PIN_SCK  10
#define PIN_MOSI 11
#define PIN_DC   12
#define PIN_CS   13

// ── Rotary encoder quadrature (direct wiring). The ROT signals are active-low,
// so the inputs use pull-ups; a closed contact pulls the pin down. The encoder
// PUSH button no longer lives here — it moved to the MCP23008 I/O expander (GP0),
// read over I2C below. (GPIO17, formerly tied high for the old hookup, is now the
// W5500 chip-select — see netcfg.cpp.)
//   ROT_A  -> GPIO14   quadrature A   (PIO in-base; A/B must be consecutive)
//   ROT_B  -> GPIO15   quadrature B
#define PIN_ENC_A   14
#define PIN_ENC_B   15

// ── Front-panel buttons + buzzer on an MCP23008 I/O expander (I2C1) ────────────
// The RP2350 exposes I2C1 SDA/SCL on GPIO6/GPIO7 (I2C0 cannot reach those pins),
// so the expander lives on the Wire1 peripheral. Its INT pin flags any button
// change on GPIO8; we read GPIO to identify the change and clear the interrupt.
//   SDA -> GPIO6   (I2C1 SDA)
//   SCL -> GPIO7   (I2C1 SCL)
//   INT -> GPIO8   (active-low, open-drain w/ external pull-up; low on change)
#define PIN_MCP_SDA 6
#define PIN_MCP_SCL 7
#define PIN_MCP_INT 8

// A2:A1:A0 strapped low → 7-bit slave address 0x20.
static const uint8_t MCP_ADDR = 0x20;

// MCP23008 register addresses (Table 1-2).
#define MCP_IODIR   0x00
#define MCP_IPOL    0x01
#define MCP_GPINTEN 0x02
#define MCP_DEFVAL  0x03
#define MCP_INTCON  0x04
#define MCP_IOCON   0x05
#define MCP_GPPU    0x06
#define MCP_INTF    0x07
#define MCP_INTCAP  0x08
#define MCP_GPIO    0x09
#define MCP_OLAT    0x0A

// Expander pin map (bit position = GPn). All buttons are active-low with pull-ups;
// GP4 is the active-high buzzer output. Bits are named by front-panel function.
#define MCP_ENC_BT (1 << 0)   // GP0  encoder push button (digit select / menu)
#define MCP_CH2_I  (1 << 1)   // GP1  select CH2 current setpoint for editing
#define MCP_CH2_ON (1 << 2)   // GP2  CH2 output toggle
#define MCP_CH2_V  (1 << 3)   // GP3  select CH2 voltage setpoint for editing
#define MCP_BUZZER (1 << 4)   // GP4  buzzer (active-high output)
#define MCP_CH1_I  (1 << 5)   // GP5  select CH1 current setpoint for editing
#define MCP_CH1_V  (1 << 6)   // GP6  select CH1 voltage setpoint for editing
#define MCP_CH1_ON (1 << 7)   // GP7  CH1 output toggle

// All pins except the buzzer (GP4) are button inputs.
static const uint8_t MCP_BTN_MASK = (uint8_t)~MCP_BUZZER;   // 0xEF

SSD1322 display(SPI1, PIN_CS, PIN_DC, PIN_RES, PIN_SCK, PIN_MOSI);

// ── Quadrature decoder (PIO) ────────────────────────────────────────────────────
// A PIO state machine (quadrature_encoder.pio, from pico-examples) samples A/B
// every ~10 sys clocks, walks the quadrature state table in hardware and keeps
// the signed edge count in its Y register, streaming it to the RX FIFO. The CPU
// takes no interrupts; serviceEncoder() just fetches the latest count. One
// mechanical detent = 4 edge counts.
#include "hardware/pio.h"
#include "quadrature_encoder.pio.h"

static PIO     encPio       = pio0;
static int     encSm        = -1;
static int32_t encLastCount = 0;   // PIO count at the previous serviceEncoder()
static int     encAccum     = 0;   // edges accumulated toward the next detent
static const int ENC_SIGN   = 1;  // flip sign if rotation goes the wrong way

static void encoderInit() {
    // Pads: inputs with pull-ups (signals are active-low). The PIO IN path
    // sees the pad regardless of function select, so plain pinMode() is enough.
    pinMode(PIN_ENC_A,  INPUT_PULLUP);
    pinMode(PIN_ENC_B,  INPUT_PULLUP);

    encSm = pio_claim_unused_sm(encPio, true);
    pio_add_program(encPio, &quadrature_encoder_program);  // needs .origin 0
    quadrature_encoder_program_init(encPio, encSm, PIN_ENC_A, 0);
    encLastCount = quadrature_encoder_get_count(encPio, encSm);
}

// Whole detents turned since the last call (sign per ENC_SIGN), remainder kept.
static int encoderReadSteps() {
    int32_t count = quadrature_encoder_get_count(encPio, encSm);
    encAccum += (int)(count - encLastCount) * ENC_SIGN;
    encLastCount = count;
    int steps = encAccum / 4;
    encAccum -= steps * 4;
    return steps;
}

// ── MCP23008 I/O expander (front-panel buttons + buzzer) ───────────────────────
// Single-register reads/writes over I2C1. The expander is configured for
// interrupt-on-change against the previous pin state (INTCON = 0), so any button
// edge pulses INT; serviceMcpButtons() reads GPIO to see which pins changed and to
// clear the interrupt, then edge-detects presses in software with a debounce.

static uint8_t mcpOlat      = 0;   // shadow of the output latch (only GP4 matters)
static uint8_t g_btnPressed = 0;   // debounced pressed bitmask (bit set = pressed)

static void mcpWrite(uint8_t reg, uint8_t val) {
    Wire1.beginTransmission(MCP_ADDR);
    Wire1.write(reg);
    Wire1.write(val);
    Wire1.endTransmission();
}

static uint8_t mcpRead(uint8_t reg) {
    Wire1.beginTransmission(MCP_ADDR);
    Wire1.write(reg);
    Wire1.endTransmission(false);                 // repeated start (no bus release)
    Wire1.requestFrom((uint8_t)MCP_ADDR, (uint8_t)1);
    return Wire1.available() ? (uint8_t)Wire1.read() : 0xFF;
}

// Drive the buzzer (GP4). Kept as a shadow write so the input pins are untouched.
static void mcpSetBuzzer(bool on) {
    if (on) mcpOlat |= MCP_BUZZER;
    else    mcpOlat &= (uint8_t)~MCP_BUZZER;
    mcpWrite(MCP_OLAT, mcpOlat);
}

static void mcpInit() {
    Wire1.setSDA(PIN_MCP_SDA);
    Wire1.setSCL(PIN_MCP_SCL);
    Wire1.begin();
    Wire1.setClock(400000);                       // 400 kHz (MCP23008 fast mode)

    mcpWrite(MCP_IODIR,   MCP_BTN_MASK);          // buttons in, GP4 (buzzer) out
    mcpWrite(MCP_GPPU,    MCP_BTN_MASK);          // pull-ups on the button inputs
    mcpWrite(MCP_IPOL,    0x00);                  // no inversion; low = pressed
    mcpWrite(MCP_INTCON,  0x00);                  // compare against previous value
    mcpWrite(MCP_DEFVAL,  0x00);
    mcpWrite(MCP_IOCON,   0x04);                  // INT open-drain (ODR=1); ext. pull-up
    mcpWrite(MCP_GPINTEN, MCP_BTN_MASK);          // interrupt-on-change for buttons
    mcpOlat = 0x00;
    mcpWrite(MCP_OLAT,    mcpOlat);               // buzzer off

    pinMode(PIN_MCP_INT, INPUT);                  // hardware pull-up holds INT high
    (void)mcpRead(MCP_GPIO);                      // clear any power-on interrupt

#if BRAIN_SERIAL_DEBUG
    uint8_t back = mcpRead(MCP_IODIR);            // bring-up sanity check
    Serial.print("MCP23008 IODIR readback: 0x");
    Serial.println(back, HEX);
    if (back != MCP_BTN_MASK)
        Serial.println("MCP23008 not responding as expected!");
#endif
}

// ── Buzzer (non-blocking) ──────────────────────────────────────────────────────
// beep() arms a timed tone; serviceBuzzer() turns it off when the deadline passes.
static uint32_t buzzerOffMs = 0;
static bool     beeperEnabled = true;   // gated by the UI "Beeper" setting

static void beep(uint16_t ms) {
    if (!beeperEnabled) return;
    mcpSetBuzzer(true);
    buzzerOffMs = millis() + ms;
}

static void serviceBuzzer() {
    if (buzzerOffMs && (int32_t)(millis() - buzzerOffMs) >= 0) {
        mcpSetBuzzer(false);
        buzzerOffMs = 0;
    }
}

// ── Heatsink NTC thermistor (brain ADC) ────────────────────────────────────────
// A 10k B3435 NTC on GPIO29 (ADC3) is the low leg of a divider with a 10k pull-up
// to 3V3; the same 3V3 rail is the ADC reference, so the reading is ratiometric and
// the exact rail voltage cancels. Node voltage falls as the heatsink heats up.
//   3V3 ── 10k ──┬── GPIO29 (ADC3)
//                └── NTC(10k @25C) ── GND
#define PIN_NTC 29
static const float NTC_PULLUP_OHM = 10000.0f;   // top resistor to 3V3
static const float NTC_R25_OHM    = 10000.0f;   // NTC nominal resistance at 25 C
static const float NTC_BETA       = 3435.0f;    // B25/85 constant (B3435)
static const float NTC_T0_K       = 298.15f;    // 25 C in kelvin
static const int   NTC_ADC_BITS   = 12;         // analogReadResolution() set in setup()
static const int   NTC_OVERSAMPLE = 16;         // raw samples averaged per read

// Read the heatsink NTC and convert to degrees C via the beta model. Returns NAN
// when the divider sits at either rail (open or shorted thermistor / bad wiring).
static float readHeatsinkTempC() {
    uint32_t acc = 0;
    for (int i = 0; i < NTC_OVERSAMPLE; i++) acc += (uint32_t)analogRead(PIN_NTC);
    const int   maxCount = (1 << NTC_ADC_BITS) - 1;
    const float ratio    = (float)acc / ((float)NTC_OVERSAMPLE * (float)maxCount);
    if (ratio <= 0.01f || ratio >= 0.99f) return NAN;   // rail: open/short, no valid temp

    // Divider: Vnode = Vcc * Rntc/(Rntc + Rpull)  ->  Rntc = Rpull * ratio/(1 - ratio).
    const float rNtc = NTC_PULLUP_OHM * ratio / (1.0f - ratio);
    // Beta equation: 1/T = 1/T0 + ln(Rntc/R25)/B.
    const float tK = 1.0f / (1.0f / NTC_T0_K + logf(rNtc / NTC_R25_OHM) / NTC_BETA);
    return tK - 273.15f;
}

// ── Chassis fan (12V 4-wire PWM) ───────────────────────────────────────────────
// A PC fan's PWM control input is on GPIO26. Speed follows the hottest measured
// temperature (Ch1 / Ch2 / heatsink) using the curve configured in the Temp and Fan
// submenu: off below "Fan start temp", jumping to "Fan min speed" there and ramping
// linearly to 100% at "Fan max temp". Standard 4-wire fan PWM runs at 25 kHz.
#define PIN_FAN 26
static const uint32_t FAN_PWM_HZ    = 25000;   // Intel 4-wire spec target (21-28 kHz)
static const uint16_t FAN_PWM_RANGE = 1000;    // analogWrite() full-scale (0.1% steps)
static const float    FAN_HYST_C    = 3.0f;    // switch-on hysteresis (anti-chatter)
static const uint32_t FAN_UPDATE_MS = 500;     // control-loop period

// Thermal setpoints, also shown (and edited) in the Temp and Fan submenu. Single
// source of truth: resolveMenuValue() renders these, the thermal service acts on them.
static uint8_t g_fanMinPct = 20;   // fan duty when it first switches on
static int     g_fanStartC = 45;   // fan switch-on temperature
static int     g_fanMaxC   = 70;   // temperature at which the fan reaches 100%
static int     g_sysOtpC   = 85;   // system over-temp trip (Temp max >= this -> outputs off)

static const float SYS_OTP_HYST_C = 5.0f;   // clear the trip this far below the setpoint

// Shared thermal state, updated by serviceThermal(): the hottest measured
// temperature (Ch1 / Ch2 / heatsink) and the latched over-temperature trip.
static float g_tempMaxC   = NAN;   // NAN until the first sample / when no sensor is valid
static bool  g_otpTripped = false; // true while the OTP latch holds the outputs off

// ── Persistent thermal setpoints (flash-backed EEPROM emulation) ───────────────
// The four Temp-and-Fan setpoints survive reboots. Layout mirrors the channel's
// storage: magic + version gate the blob and a CRC16 guards it. Saved when a
// Temp-and-Fan edit is committed; loaded once at boot (defaults stand if the blob is
// absent or corrupt).
#define BRAIN_EEPROM_SIZE     256
#define THERMAL_STORE_ADDR    0
#define THERMAL_STORE_MAGIC   0x54484D31u   /* 'THM1' */
#define THERMAL_STORE_VERSION 1

struct ThermalStore {
    uint32_t magic;
    uint16_t version;
    uint8_t  fanMinPct;
    uint8_t  fanStartC;
    uint8_t  fanMaxC;
    uint8_t  sysOtpC;
    uint16_t crc;
};

// CRC16-CCITT (poly 0x1021, init 0xFFFF), same routine as the channel storage.
static uint16_t crc16(const uint8_t *data, uint16_t len) {
    uint16_t crc = 0xFFFFu;
    for (uint16_t i = 0; i < len; i++) {
        crc ^= (uint16_t)data[i] << 8;
        for (uint8_t b = 0; b < 8; b++)
            crc = (crc & 0x8000u) ? (uint16_t)((crc << 1) ^ 0x1021u) : (uint16_t)(crc << 1);
    }
    return crc;
}

// Persist the current thermal setpoints to flash. Called after a committed edit.
static void thermalSettingsSave() {
    ThermalStore s;
    s.magic     = THERMAL_STORE_MAGIC;
    s.version   = THERMAL_STORE_VERSION;
    s.fanMinPct = g_fanMinPct;
    s.fanStartC = (uint8_t)g_fanStartC;
    s.fanMaxC   = (uint8_t)g_fanMaxC;
    s.sysOtpC   = (uint8_t)g_sysOtpC;
    s.crc       = crc16((const uint8_t *)&s, offsetof(ThermalStore, crc));
    EEPROM.put(THERMAL_STORE_ADDR, s);
    EEPROM.commit();   // RP2350 EEPROM emulation is a RAM shadow; commit flushes it
}

// Load persisted setpoints at boot, clamped to the editor ranges. Leaves the
// compiled-in defaults in place if the blob is absent or fails validation.
static void thermalSettingsLoad() {
    ThermalStore s;
    EEPROM.get(THERMAL_STORE_ADDR, s);
    if (s.magic != THERMAL_STORE_MAGIC || s.version != THERMAL_STORE_VERSION) return;
    if (s.crc != crc16((const uint8_t *)&s, offsetof(ThermalStore, crc)))      return;
    g_fanMinPct = s.fanMinPct > 100 ? 100 : s.fanMinPct;
    g_fanStartC = s.fanStartC > 100 ? 100 : s.fanStartC;
    g_fanMaxC   = s.fanMaxC   > 100 ? 100 : s.fanMaxC;
    g_sysOtpC   = s.sysOtpC   < 40 ? 40 : (s.sysOtpC > 120 ? 120 : s.sysOtpC);
}

// ── Brain operating-hours meter (flash-backed EEPROM emulation) ────────────────
// The brain's own hour-meter: accumulated powered-on seconds, persisted so the
// "Brain runtime" system row survives reboots. Its own blob (magic/version/CRC)
// in a separate EEPROM slot from the thermal store. RP2350 EEPROM.commit() flushes
// the whole 256 B shadow to one flash sector, so we save on a slow cadence to
// bound sector-erase wear; up to BRAIN_RUNTIME_SAVE_S of the current session is
// lost on an unexpected power-off, which never changes the whole-hours readout.
#define BRAIN_RUNTIME_STORE_ADDR    32
#define BRAIN_RUNTIME_STORE_MAGIC   0x42525431u   /* 'BRT1' */
#define BRAIN_RUNTIME_STORE_VERSION 1
#define BRAIN_RUNTIME_SAVE_S        600u          /* flush every 10 min of runtime */

struct BrainRuntimeStore {
    uint32_t magic;
    uint16_t version;
    uint32_t seconds;
    uint16_t crc;
};

static uint32_t g_brainRuntimeS = 0;   // total accumulated powered-on seconds

static void brainRuntimeSave() {
    BrainRuntimeStore s;
    s.magic   = BRAIN_RUNTIME_STORE_MAGIC;
    s.version = BRAIN_RUNTIME_STORE_VERSION;
    s.seconds = g_brainRuntimeS;
    s.crc     = crc16((const uint8_t *)&s, offsetof(BrainRuntimeStore, crc));
    EEPROM.put(BRAIN_RUNTIME_STORE_ADDR, s);
    EEPROM.commit();
}

static void brainRuntimeLoad() {
    BrainRuntimeStore s;
    EEPROM.get(BRAIN_RUNTIME_STORE_ADDR, s);
    if (s.magic != BRAIN_RUNTIME_STORE_MAGIC || s.version != BRAIN_RUNTIME_STORE_VERSION) {
        brainRuntimeSave();   // seed a zeroed, valid blob
        return;
    }
    if (s.crc != crc16((const uint8_t *)&s, offsetof(BrainRuntimeStore, crc))) return;
    g_brainRuntimeS = s.seconds;
}

// Advance the brain hour-meter from elapsed millis() and flush to flash once a
// full BRAIN_RUNTIME_SAVE_S has accumulated since the last save. Called every loop.
static void serviceBrainRuntime() {
    static uint32_t lastMs   = 0;
    static uint32_t fracMs   = 0;
    static uint32_t savedS   = 0;
    static bool     inited   = false;
    if (!inited) { lastMs = millis(); savedS = g_brainRuntimeS; inited = true; }

    uint32_t now = millis();
    fracMs += (uint32_t)(now - lastMs);
    lastMs  = now;
    if (fracMs >= 1000u) { g_brainRuntimeS += fracMs / 1000u; fracMs %= 1000u; }

    if (g_brainRuntimeS - savedS >= BRAIN_RUNTIME_SAVE_S) {
        brainRuntimeSave();
        savedS = g_brainRuntimeS;
    }
}

static void fanInit() {
    analogWriteFreq(FAN_PWM_HZ);
    analogWriteRange(FAN_PWM_RANGE);
    analogWrite(PIN_FAN, FAN_PWM_RANGE);   // fail-safe: full speed until the first temp read
}

// Hottest currently-valid temperature (Ch1 / Ch2 telemetry + heatsink NTC), or NAN
// if none is available.
static float governingTempC() {
    float best = NAN;
    const ChannelStatus &s1 = channel_status(0);
    const ChannelStatus &s2 = channel_status(1);
    if (s1.linkUp) { float t = s1.temp_cC / 100.0f; if (isnan(best) || t > best) best = t; }
    if (s2.linkUp) { float t = s2.temp_cC / 100.0f; if (isnan(best) || t > best) best = t; }
    float ths = readHeatsinkTempC();
    if (!isnan(ths) && (isnan(best) || ths > best)) best = ths;
    return best;
}

// Fan duty (%) on the ramp for temperature t, ignoring the on/off latch: min% at or
// below the start temp, 100% at or above the max temp, linear in between.
static uint8_t fanRampPct(float t) {
    if (g_fanMaxC <= g_fanStartC) return 100;   // guard a degenerate/inverted curve
    if (t <= g_fanStartC) return g_fanMinPct;
    if (t >= g_fanMaxC)   return 100;
    float frac = (t - (float)g_fanStartC) / (float)(g_fanMaxC - g_fanStartC);
    int pct = (int)g_fanMinPct + (int)(frac * (100 - (int)g_fanMinPct) + 0.5f);
    return (uint8_t)(pct > 100 ? 100 : pct);
}

// Apply the fan curve for governing temperature t (no timer of its own). The fan
// latches on at "Fan start temp" and off only after dropping FAN_HYST_C below it, so
// it doesn't chatter around the threshold. Unknown temperature -> full (fail-safe).
static void fanApply(float t) {
    static bool fanOn    = true;   // fail-safe until the first evaluation
    static int  lastDuty = -1;
    uint8_t pct;
    if (isnan(t)) {
        pct   = 100;                   // no valid sensor: full speed
        fanOn = true;
    } else {
        if (fanOn) { if (t < (float)g_fanStartC - FAN_HYST_C) fanOn = false; }
        else       { if (t >= (float)g_fanStartC)             fanOn = true;  }
        pct = fanOn ? fanRampPct(t) : 0;
    }

    int duty = (int)pct * FAN_PWM_RANGE / 100;
    if (duty != lastDuty) {
        analogWrite(PIN_FAN, duty);
        lastDuty = duty;
    }
}
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
void loop() {
    channel_link_task();     // drain both channel UARTs, update telemetry + link state
    serviceLinkResync();     // re-send setpoints/output on link-up; disarm on link-down
    serviceLinkHeartbeat();  // ping both channels so their comms-loss watchdog stays fed
    serviceLinkSettingsPoll(); // slow re-poll of settings (keeps Runtime row fresh)
    serviceBrainRuntime();   // accumulate the brain's own operating hours
    serviceSetpointPersist(); // debounced flush of V/I setpoints ("Remember set")
    serviceMcpButtons();   // refresh button state (incl. encoder GP0) before dispatch
    serviceEncoder();
    serviceBuzzer();
    serviceThermal();      // hottest temp -> over-temp trip + chassis fan PWM

    netcfg_task();         // accept/serve SCPI TCP clients; DHCP maintenance
    serviceUsbScpi();      // SCPI over the USB CDC console
    scpi_task();           // fold channel events into the SCPI error queue/status

    const uint32_t now = millis();

    if (uiPage == PAGE_MAIN) {
        // ~20 fps readout refresh from live telemetry.
        static uint32_t lastReadout = 0;
        if ((uint32_t)(now - lastReadout) >= 50) {
            lastReadout = now;
            updateMeasFromTelemetry();
            drawChannelHeader(0);
            drawChannelHeader(1);
            drawDynamic(ch1,   0);
            drawDynamic(ch2, 128);
            flushDynamic(0);
            flushDynamic(128);
        }
    } else if (uiPage == PAGE_CAL) {
        if (!channel_status((uint8_t)calCh).linkUp || g_otpTripped) {
            // Lost the channel or over-temperature: abandon the calibration.
            beep(200);
            calExit();
        } else if (calStep == CAL_S_ENTRY) {
            // Refresh the entry page so the live measurement and the
            // settling banner keep tracking.
            static uint32_t lastCal = 0;
            if ((uint32_t)(now - lastCal) >= 300) {
                lastCal = now;
                drawCalPage();
            }
        }
    } else if (uiPage == PAGE_SUBMENU && (submenuIdx <= SUB_FAN || submenuIdx == SUB_NET)) {
        // Channel / fan submenus mirror live telemetry; the Network submenu mirrors
        // link + DHCP status. Refresh a few times a second while the page is open.
        static uint32_t lastMenu = 0;
        if ((uint32_t)(now - lastMenu) >= 300) {
            lastMenu = now;
            drawSubmenu();
        }
    }

    rp2040.wdt_reset();    // completed a pass: the watchdog stays happy
}

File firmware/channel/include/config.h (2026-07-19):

/**
 * config.h - Board pin map, build-time constants and tunables for the
 *            power-supply CHANNEL firmware (ATtiny1614 @ 3.3 V).
 *
 * All hardware-specific numbers live here so the rest of the code stays
 * portable and readable. Pins use megaTinyCore's PIN_Pxn macros.
 *
 * NOTE ON ADC_CS: the requirements doc lists ADC_CS on PA3, which collides
 * with SCK. The bus is shared (MOSI/MISO/SCK on PA1/PA2/PA3) so ADC_CS must
 * be its own line; it is wired to PA4 (the ATtiny1614 default SPI SS).
 */
#ifndef CHANNEL_CONFIG_H
#define CHANNEL_CONFIG_H

#include <Arduino.h>

/* ------------------------------------------------------------------ */
/* Pin map (ATtiny1614, 14-pin SOIC)                                  */
/* ------------------------------------------------------------------ */

/* Shared SPI bus (handled by the SPI library on the default pins):
 *   MOSI = PA1, MISO = PA2, SCK = PA3                                 */
#define PIN_ADC_CS      PIN_PA4   /* ADS1118    chip select (active low) */
#define PIN_DAC_CS      PIN_PA7   /* MCP48FVB22 chip select (active low) */
#define PIN_DAC_LAT     PIN_PA6   /* MCP48FVB22 latch (active low)       */

/* Output enable lines */
#define PIN_EN_DCDC     PIN_PB1   /* Enable_DCDC : pre-regulator (buck)  */
#define PIN_EN_LIN      PIN_PA5   /* Enable_lin  : linear post-regulator */

/* Thermistor divider (on-chip ADC input) */
#define PIN_NTC         PIN_PB0   /* 10k NTC, Rtop=10k to VDD, Rbot=NTC  */

/* UART to the Brain is USART0 on PB2(TX)/PB3(RX) -> the 'Serial' object */
#define BRAIN_UART      Serial
#define BRAIN_BAUD      1000000UL   /* 1 Mbps; exact at F_CPU=16 MHz (BAUD reg = 64) */

/* ------------------------------------------------------------------ */
/* NTC thermistor (10k, B=3380K, beta model)                          */
/* ------------------------------------------------------------------ */
#define NTC_R_TOP_OHMS      10000.0f   /* fixed top resistor to VDD       */
#define NTC_R0_OHMS         10000.0f   /* NTC nominal resistance @ T0     */
#define NTC_T0_KELVIN       298.15f    /* 25 C                            */
#define NTC_BETA            3380.0f    /* B-constant (K)                  */
#define NTC_ADC_BITS        10         /* analogRead resolution we use    */

/* ------------------------------------------------------------------ */
/* Thermal protection                                                 */
/* ------------------------------------------------------------------ */
/* The trip point is runtime-settable per channel (CMD_SET_OTP, persisted in
 * the settings EEPROM, clamped to OTP_MIN_C..OTP_MAX_C). This is only the value
 * used to seed a blank EEPROM. Recovery is TEMP_OTP_HYST_C below the trip. */
#define TEMP_OTP_DEFAULT_C  60u        /* shut output off at/above this   */
#define TEMP_OTP_HYST_C     5.0f       /* re-arm this far below the trip  */

/* ------------------------------------------------------------------ */
/* Comms-loss watchdog                                                */
/* ------------------------------------------------------------------ */
/* While the output is on, the Brain must be heard from within this
 * window or the channel trips the output off (safe state). The Brain
 * pings every LINK_HEARTBEAT_MS (250) so a healthy link never trips;
 * this leaves ~4 missed heartbeats of margin against loop jitter.    */
#define COMMS_TIMEOUT_MS    1000u
#define TEMP_SELFTEST_MIN_C (-10.0f)   /* startup must be within this ... */
#define TEMP_SELFTEST_MAX_C 60.0f      /* ... range                       */

/* ------------------------------------------------------------------ */
/* DAC (MCP48FVB22) - internal band gap, gain 1x -> 0..2.44 V FS       */
/* ------------------------------------------------------------------ */
#define DAC_FULLSCALE_V     2.44f      /* VRL = 2 x 1.22V band gap, G=1x  */
#define DAC_MAX_CODE        4095u      /* 12-bit                          */
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

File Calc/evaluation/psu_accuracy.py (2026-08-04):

#!/usr/bin/env python3
"""Output-voltage accuracy evaluation for the 2-Channel Pre-Reg Power Supply.

Ramps one PSU channel from 0 V to 36 V in 500 mV steps and, at every step,
compares three numbers:

    v_set   the SCPI setpoint written to the PSU          (what we asked for)
    v_psu   the PSU's own readback, MEAS:VOLT?            (what it thinks it did)
    v_dmm   a Siglent SDM3065X 6.5-digit DMM reading      (ground truth)

and reports the two deviations that matter:

    setpoint error  = v_set - v_dmm     (DAC + Vset scaling path, "CAL VSET")
    readback error  = v_psu - v_dmm     (ADC + Vsense path,      "CAL VMEAS")

Both instruments are driven over raw SCPI/TCP on port 5025, so no VISA runtime
or pyvisa is required.  Outputs a CSV, a summary report and light/dark PNG
plots into ``Calc/evaluation/results/``.

Wiring
------
PSU channel output --> SDM3065X DC-V input, sense leads at the PSU binding
posts (or, better, at the DUT end you care about).  The ramp is meant to be run
into an *open circuit*: the DMM draws <= ~4 uA, so the current reading stays at
zero and any current above ``--abort-current`` aborts the run as a wiring
mistake.

Examples
--------
    py psu_voltage_accuracy.py --psu 192.168.1.50 --dmm 192.168.1.51
    py psu_voltage_accuracy.py --psu psu.local --dmm 192.168.1.51 --channel 2
    py psu_voltage_accuracy.py --simulate            # no hardware, exercises plots
    py psu_voltage_accuracy.py --replot results/ramp_20260803_101500.csv
"""

from __future__ import annotations

import argparse
import csv
import math
import random
import socket
import sys
import time
from dataclasses import dataclass, asdict
from datetime import datetime
from pathlib import Path

import numpy as np

HERE = Path(__file__).resolve().parent
RESULTS_DIR = HERE / "results"

SCPI_PORT = 5025

# ---------------------------------------------------------------------------
# Chart palette (dataviz reference instance, categorical slots 1 and 2).
# Two series only; slots 1/2 are an adjacent pair and pass the CVD gates in
# both modes as documented, so they are used verbatim.
# ---------------------------------------------------------------------------
THEMES = {
    "light": dict(
        surface="#fcfcfb", page="#f9f9f7",
        ink="#0b0b0b", ink2="#52514e", muted="#898781",
        grid="#e1e0d9", axis="#c3c2b7",
        s1="#2a78d6", s2="#eb6834",
    ),
    "dark": dict(
        surface="#1a1a19", page="#0d0d0d",
        ink="#ffffff", ink2="#c3c2b7", muted="#898781",
        grid="#2c2c2a", axis="#383835",
        s1="#3987e5", s2="#d95926",
    ),
}


@dataclass(frozen=True)
class Quantity:
    """Everything that differs between a voltage ramp and a current ramp."""
    name: str          # "voltage" / "current"
    unit: str          # "V" / "A"
    munit: str         # "mV" / "mA"
    set_cmd: str       # SCPI header that writes the setpoint
    meas_cmd: str      # SCPI query that reads it back
    aux_cmd: str       # the companion reading logged alongside
    aux_munit: str     # unit of that companion reading
    dmm_fn: str        # DMM function for CONFigure / NPLC / AZ
    cal_set: str       # calibration path for the setpoint chain
    cal_meas: str      # calibration path for the measure chain
    dec: int           # decimals used when writing the setpoint
    set_lsb_m: float   # DAC step, in munit (for interpreting the sawtooth)
    meas_lsb_m: float  # ADC step, in munit


QUANTITIES = {
    # DAC full scale = 2.44 V x DEFAULT_V_GAIN 15 = 36.6 V -> 8.94 mV/code.
    # ADC +-4.096 V FSR = 125 uV/LSB, x14.42 to the output -> 1.80 mV.
    "voltage": Quantity("voltage", "V", "mV", "VOLT", "MEAS:VOLT?", "MEAS:CURR?", "mA",
                        "VOLT:DC", "VSET", "VMEAS", 3, 36.6 / 4096 * 1000, 1.80),
    # DAC full scale = 2.44 V / DEFAULT_I_DIV 1.2 = 2.033 A -> 0.496 mA/code.
    # ADC 125 uV/LSB / 1.225 V/A -> 0.102 mA.
    "current": Quantity("current", "A", "mA", "CURR", "MEAS:CURR?", "MEAS:VOLT?", "mV",
                        "CURR:DC", "ISET", "IMEAS", 4, 2.4402 / 1.2 / 4096 * 1000, 0.102),
}

SERIES_SET = "Setpoint error (setpoint - DMM)"
SERIES_MEAS = "Readback error (PSU measurement - DMM)"


class ScpiError(RuntimeError):
    pass


# ---------------------------------------------------------------------------
# Transport
# ---------------------------------------------------------------------------
class ScpiSocket:
    """Line-oriented SCPI over a raw TCP socket (port 5025)."""

    def __init__(self, host: str, port: int = SCPI_PORT, timeout: float = 10.0,
                 name: str = "instrument", verbose: bool = False,
                 retries: int = 0, retry_delay: float = 3.0):
        self.host = host
        self.port = port
        self.timeout = timeout
        self.name = name
        self.verbose = verbose
        self.retries = retries
        self.retry_delay = retry_delay
        self._sock: socket.socket | None = None
        self._buf = b""

    def open(self) -> "ScpiSocket":
        try:
            self._sock = socket.create_connection((self.host, self.port), timeout=self.timeout)
        except OSError as exc:
            raise ScpiError(f"{self.name}: cannot connect to {self.host}:{self.port} ({exc})") from exc
        self._sock.settimeout(self.timeout)
        self._sock.setsockopt(socket.IPPROTO_TCP, socket.TCP_NODELAY, 1)
        return self

    def close(self) -> None:
        if self._sock is not None:
            try:
                self._sock.close()
            finally:
                self._sock = None

    def __enter__(self) -> "ScpiSocket":
        return self.open()

    def __exit__(self, *exc) -> None:
        self.close()
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

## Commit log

2026-06-09 Add KiCad 10 project: 2-channel pre-regulated power supply
    [CH1AuxPowerSupplys.kicad_sch, CH1_Volt_Curr_meas.kicad_sch, Ch1Power.kicad_sch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]
2026-06-09 test commit
    [DualPreRegPowerSupply.kicad_pcb]
2026-06-09 test commit 2
    [DualPreRegPowerSupply.kicad_pcb]
2026-06-10 changed pass element drive
    [Ch1Power.kicad_sch, Control.kicad_sch, DualPreRegPowerSupply.kicad_pcb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]
2026-06-13 added Ch2 and removed global power flags
    [Ch2Power.kicad_sch, Control.kicad_sch, DAC_ADC.kicad_sch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]
2026-06-15 channel 2
    [Ch2Power.kicad_sch, DAC_ADC2.kicad_sch, DCDCTracking2.kicad_sch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]
2026-06-16 added loop calc
    [Ch1Power.kicad_sch, Control.kicad_sch, DCDCTracking.kicad_sch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]
2026-06-18 add adc and dac estimate
    [Control.kicad_sch, DualPreRegPowerSupply.kicad_pcb, Linear_PostReg.kicad_sch]
2026-06-18 moove files and add firmware folder
    [CH1AuxPowerSupplys.kicad_sch, CH1_Volt_Curr_meas.kicad_sch, Ch1Power.kicad_sch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]
2026-06-19 add diodes for clamping
    [Control.kicad_sch, DCDCTracking.kicad_sch, DualPreRegPowerSupply.kicad_pcb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]
2026-06-22 added front PCB to repo
    [CH1AuxPowerSupplys.kicad_sch, CH1_Volt_Curr_meas.kicad_sch, Ch1Power.kicad_sch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]
2026-06-23 added readme
    [DualPreRegPowerSupply.kicad_pcb]
2026-06-23 cleanup not used schematics
    [CH1AuxPowerSupplys.kicad_sch, CH1_Volt_Curr_meas.kicad_sch, DAC.kicad_sch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]
2026-07-03 stability calc
    [DAC_ADC.kicad_sch, DCDCTracking.kicad_sch, DualPreRegPowerSupply.kicad_pcb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]
2026-07-04 calc and cleanup
    [2ChannelPSU_bom.csv, 2ChannelPSU_designators.csv, 2ChannelPSU_positions.csv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]
2026-07-06 12mA minimum-load sink: bound low-bias beta corner in stability calc
2026-07-17 while build
    [Digi_Power.kicad_sch, Front Panel.kicad_pcb, Front Panel.kicad_sch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]
2026-07-17 brain: add main firmware with brain<->channel UART comms
    Add firmware/brain/main, the production brain firmware built on the
    UI-test UI plus a UART link to the two ATtiny1614 channels:
    - channel_link module: per-link framed-protocol RX parser + command API
    (set V/I/output, cal, fault reset), telemetry+health snapshot per
    channel. CH1=UART0 (Serial1, GP0/1), CH2=UART1 (Serial2, GP4/5),
    1 Mbps, wiring traced from Control.kicad_sch.
    - main.cpp: setpoints pushed to the channel on edit, CHx_ON buttons
    toggle+send output, readout and Channel/Fan submenus show live
    telemetry, header colour tracks link/output state, setpoints resync
    on link-up.
    channel: fix clock and set real uncalibrat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
    [calibration.cpp, channel_link.cpp, config.h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]
2026-07-17 channel: switch to 16 MHz internal oscillator
    Set board_build.f_cpu to 16 MHz (was 20 MHz). OSCCFG fuse must be
    re-burned with 'pio run -e ATtiny1614 -t fuses' (writes 0x01); a plain
    -t upload does not touch fuses. 1 Mbps link stays bit-exact (BAUD=64).
    [config.h]
2026-07-17 brain: fix spurious Comm FAIL blips on healthy channel link
    channel_link_task() captured 'now' before draining the UART, but each
    parsed telemetry frame set lastRxMs to a later millis(). When the parse
    crossed a ms tick, lastRxMs landed past the stale 'now' and the unsigned
    (now - lastRxMs) underflowed to ~4e9, tripping the 500 ms link timeout
    and flashing 'Comm FAIL' on an otherwise healthy link (fps=10, crc=0,
    ovf=0). Fixed by comparing a freshly sampled millis() with signed math.
    Also enlarge the RP2350 RX ring to 256 B as insurance against the
    blocking per-byte SSD1322 flush, and add an rxOverflows counter.
    [channel_link.cpp]
2026-07-17 raised max volatge to 36V
2026-07-17 channel: fix V/I swap from ADS1118 re-arm during read
    ads1118_read() re-wrote the Config word with SS set, restarting a
    conversion of the old channel; the mux written by the following
    ads1118_start() was ignored until that stray conversion finished, so
    every result was attributed to the other channel (Vdisp stuck near 0,
    Idisp tracking the voltage sense, full-scale 3.413 A clip once the
    cross-fed autoscaler hit the +-0.256 V range at Vout > 3.84 V).
    Read now clocks DIN = 0x0000 (invalid NOP), leaving the Config register
    untouched and the device powered down until the next start.
    [ads1118.cpp, measure.cpp]
2026-07-18 brain: remember edited digit per CH/V/I field
    Replace the single global selDigit cursor with selDigitFor[ch][param] so
    switching edit targets restores the digit last edited there instead of
    sharing one cursor across all four setpoints.
    [main.cpp]
2026-07-18 channel+brain: turn output off on comms loss
    Add a link-loss watchdog so a dead Brain or unplugged UART can't leave a
    channel's output live.
    Channel: while in ST_RUN, if no valid Brain frame arrives within
    COMMS_TIMEOUT_MS (1000 ms) the FSM disables the output and drops to
    ST_IDLE + emits EVT_COMMS_TIMEOUT. comms_since_rx_ms() is fed on every
    good-CRC frame (a link too noisy to pass CRC counts as lost).
    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
2026-07-18 meas: real 0.1 mA current resolution; V 3 dp / I 4 dp readout
    Measured voltage now shows 3 decimals and current 4 decimals on the
    panel readout, the CH1/CH2 settings submenu, and the UI-test mock.
    The 4th current digit was structurally always 0: the channel rounded
    the measured current to whole mA (lroundf) before telemetry, and every
    layer downstream carried int32 mA. The channel now stores and sends
    current in 0.1 mA units (meas_i_dmA = round(mA * 10)); the brain parses
    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
2026-07-18 channel+brain: per-channel V/I measurement averaging
    Add an independent moving-average window (1..32 samples) for the measured
    voltage and current on each channel. The window lengths are set from the
    brain and persisted in the channel's EEPROM, so they survive power cycles.
    Channel:
    - settings module + separate SettingsStore EEPROM blob (own magic/version/
    CRC, kept apart from CalStore so evolving settings never wipes cal)
    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
2026-07-18 brain: heatsink NTC temp, temperature fan control + SYS OTP
    Add brain-side thermal management driven by the hottest measured
    temperature (Ch1/Ch2 telemetry + heatsink NTC):
    - Heatsink NTC (10k B3435, 10k pull-up) on GPIO29 via ratiometric ADC +
    beta model; shown live in the Temp and Fan submenu.
    - 4-wire fan PWM at 25 kHz on GPIO26: off below start temp, min% at
    start ramping to 100% at max temp, with switch-off hysteresis and
    full-speed fail-safe when no sensor is valid.
    - SYS OTP: latching over-temp trip forces both outputs off (and blocks
    re-enable) once Temp max reaches the setpoint, clearing 5 C below.
    Temp max now includes the heatsink so it matches the trip variable.
    - SYS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
    [main.cpp]
2026-07-19 channel+brain: manual 2-point calibration wizard
    Brain: guided Manual Cal V/I wizard (PAGE_CAL) started from the channel
    submenu. Start must be confirmed with the channel's V button; the wizard
    shows DMM hook-up instructions, drives the output to two points (V: 2/30 V
    open-circuit, I: 0.2/1.8 A through the DMM ammeter) and takes the dialled-in
    DMM reading for both the set and measure path of each point. Points and
    commits are ACK-verified with retries -- a commit frame sent right behind
    the channel's blocking EEPROM write used to be dropped silently, leaving
    the measure path on default coefficients -- with an error screen when the
    channel never confirms. Placeholder "Cal values" rows removed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
    [calibration.cpp, channel_link.cpp, comms.cpp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]
2026-07-19 channel+brain: operating-hours meter (per-channel + brain runtime)
    Replace the placeholder "0 h" Runtime rows with real hour-meters that
    count powered-on time and survive reboots.
    Channel: new runtime module accumulates elapsed millis() into a persistent
    seconds counter (own EEPROM RuntimeStore blob, isolated from cal/settings so
    its write churn stays off their guard cells; flushed every
    RUNTIME_SAVE_INTERVAL_S = 300 s to bound wear). The total rides the
    CMD_SETTINGS reply (SETTINGS_PAYLOAD_LEN 3 -> 7, +uint32 runtime_s).
    Brain: its own flash-backed hour-meter (separate BrainRuntimeStore slot,
    flushed every 10 min), plus a 10 s background settings re-poll so the channel
    Runtime row stays f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
    [channel_link.cpp, comms.cpp, config.h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]
2026-07-19 brain: default the set-value digit cursor to index 1
    Voltage boots with the cursor on the ones digit (just before the decimal)
    and current on the tenths digit (just after), instead of the far-right
    hundredths/thousandths digit, so the encoder lands on the digits users
    adjust most.
2026-07-19 brain: implement Beeper toggle + Remember-set setpoint persistence
    UI "Beeper" and System "Remember set" were dead placeholders. Wire both
    into the existing submenu edit path as boolean toggle rows:
    - Beeper: commitEdit now drives beeperEnabled (was read-only), so the
    buzzer can actually be silenced; the row shows live On/Off.
    - Remember set: new flash-backed SetpointStore (magic/version/CRC) in its
    own EEPROM slot persists the flag plus all four V/I setpoints. Restored
    at boot when the flag is on; main-page edits are saved on a 4 s debounce
    to bound flash wear, and toggling the flag persists immediately.
    Output on/off state is deliberately not remembered (avoids a live output
    re-e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
    [main.cpp]
2026-07-19 brain: merge single-item UI submenu into System
    The UI submenu held only Beeper, so fold it into System (now: FW version,
    Remember set, Beeper, Brain runtime) and drop the standalone UI entry. The
    Settings overview goes from 6 submenus to 5. Toggle plumbing just moves from
    SUB_UI/UIITEM_BEEPER to SUB_SYS/SYSITEM_BEEPER; behaviour is unchanged. The
    live-refresh gate (submenuIdx <= SUB_FAN) still holds since Fan stays index 2.
    Spec (Settings.md) updated to match.
2026-07-21 channel: widen ADS1118 single-shot wait 9->15ms
    A slow-oscillator ADS1118 unit converts in ~9-11ms (vs 7.8ms nominal at
    128 SPS) and returns ~0 when read before the conversion completes. At the
    old 9ms wait the result beat between the true code and 0 as the conversion
    time drifted across the threshold, dropping measured V/I to ~0 for scattered
    samples. Diagnosed via a temporary Brain USB debug dump: on glitch samples
    the double-read agreed (r1==r2) and the config readback was valid, so the
    register itself held ~0 -- an incomplete conversion, not a bus error or reset.
    9ms glitched, 12/15/20ms clean. 15ms clears the worst-case unit with margin;
    the ~33Hz V+I sample rate is still ample.
    Co-Aut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
    [ads1118.cpp]
2026-07-21 docs: correct brain I/O expander to MCP23008 (was TCAL9539RPWR)
    Firmware uses an MCP23008 on I2C1 at 400 kHz; align the requirement
    with the actual part and note the link speed.
2026-07-22 channel: gate DAC on output state + sequenced turn-on
    While off, park the DAC at Vset=0 / Iset=full-scale instead of holding the
    last setpoint. Setpoints are still remembered in g_state but only written to
    the Vset DAC while energized. Turn-on now sequences: Iset -> set current,
    enable pins (DCDC, 70ms settle, linear), then Vset -> set voltage. Disable
    parks the DAC before dropping the rails; fault relies on the same park.
2026-07-25 brain: fix setpoint/runtime persistence CRC over padded structs
    The persistence CRC was computed with `sizeof(s) - sizeof(s.crc)`, which
    only excludes the crc field when the struct has no trailing padding.
    SetpointStore and BrainRuntimeStore both end on a uint16_t crc after
    wider members, so the compiler pads sizeof past the crc field; the length
    then covered the crc bytes themselves. Save computed the CRC over
    uninitialized crc bytes, load recomputed over the stored ones -> the
    check always failed and the blob was discarded, so V/I setpoints (and the
    brain hour-meter) never restored across reboots.
    Use offsetof(Struct, crc) for the CRC length everywhere, correct
    regardless of padding. Ther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
    [main.cpp]
2026-07-25 brain: add SCPI remote control over W5500 Ethernet + USB CDC
    Implements the full firmware/SCPI/commands.md set on the brain, served over a
    W5500 TCP socket (port 5025) and the USB CDC console.
    - scpi.cpp/.h: transport-agnostic SCPI-1999/IEEE-488.2 parser (error queue,
    QUES/OPER status registers, channel lists (@1,2), MIN|MAX|DEF), translating to
    the channel link + brain_api.h so remote and panel share one setpoint/output
    state.
    - netcfg.cpp/.h: W5500 bring-up on hardware SPI0 (CS17/SCK18/MOSI19/MISO20/RST21),
    persisted LAN config (EEPROM, chip-id MAC), bounded/self-healing DHCP, and the
    SCPI TCP server with a 4-client pool.
    - brain_api.h: hooks (in main.cpp) bridging SCPI to the a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
    [main.cpp, netcfg.cpp]
2026-07-27 brain: stop DHCP maintain() from stalling the main loop
    With DHCP enabled and no server answering, the front panel became
    unusable and both channel links flapped: the brain was deaf for 6.02 s
    out of every 6.02 s, leaving a ~20 ms responsive window between stalls.
    Cause is the lease check in the vendored Ethernet library (Dhcp.cpp
    checkLease): its rebind arm also matches _dhcp_state == STATE_DHCP_START,
    which is exactly the state a failed lease attempt leaves behind, with
    _rebindInSec still 0. So every Ethernet.maintain() call re-ran the fully
    blocking request_DHCP_lease() at the timeout stored by the last begin() --
    the 6000 ms boot value. Called once per loop(), that blocks 6 s, returns,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
    [netcfg.cpp]
2026-08-03 brain: don't stall boot on DHCP when no cable is plugged in
    Powering up without an Ethernet cable left the front panel unresponsive
    for ~6.6 s: the readout was already drawn, but setpoints could not be
    adjusted until netcfg_init() returned. Two blocking waits accounted for
    it.
    Ethernet.begin(mac, timeout, responseTimeout) spins until it holds a
    lease or the budget expires, so with no link it always burned the full
    NET_DHCP_INIT_TIMEOUT_MS (6000 ms). Gate that attempt on the PHY
    reporting link-up -- linkStatus() probes and initialises the chip
    itself, so it is safe before any begin() and costs one SPI read. With no
    cable the interface is now brought up unaddressed and acquisition is
    left to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
    [netcfg.cpp]
2026-08-03 calc: remove superseded loop and DCDC design files
    Drops the "simple loops" KiCad sources (V/I loop compensator capture),
    the two LMR51606Y buck design notes, and the loose CC/CV and tracking
    DCDC feedback scratch notes. The rendered "simple loops.pdf" is kept as
    the visual record of the schematic.
    [I_loop.kicad_sch, V_loop.kicad_sch, simple loops.kicad_pcb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]
2026-08-03 docs: rewrite README to describe the project
    The README was a stub with two KiCanvas links. Replace it with a real
    description of the instrument: specs, the tracking-buck + linear post-reg
    power path, the brain/channel control split, both KiCad projects, firmware
    build instructions, SCPI remote control, calibration, power input, and the
    design calculations that back the component values.
    Also add a photo of the assembled front panel, and correct the SCPI
    reference, which still documented a 35 V limit and a stale *IDN? string;
    config.h clamps to 36 V and the firmware reports PSU-2CH-36V2A / 0.2.0.
2026-08-04 brain: bound the W5500 driver's unbounded busy-waits
    The vendored Arduino Ethernet 2.0.2 driver busy-waits on the W5x00 with no
    upper bound in four places. All of them are reached from loop() via the SCPI
    TCP server, so an unbounded wait does not merely stall the network: it stops
    the front panel, the USB console and the channel-link watchdogs dead.
    socketSend() was the cause of the "brain freezes during sustained SCPI
    sessions" fault. It waits for W5500 TX buffer space and leaves the loop only
    if the socket drops out of ESTABLISHED/CLOSE_WAIT. A peer that stops reading
    while keeping the connection open advertises a zero window, so the chip never
    frees TX space and the socket stays perfectl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
2026-08-04 brain: reclaim SCPI sessions and bound per-pass RX work
    Two independent problems in the client pool, both confirmed on the bench.
    A slot was freed only when connected() went false, i.e. when the peer closed
    properly. A peer that vanishes without a FIN (cable pulled, host slept,
    machine powered off) leaves its socket ESTABLISHED forever, so its slot is
    never reclaimed. Park four such sessions and the instrument is unreachable
    over LAN with nothing whatsoever wrong with loop() - a good match for the
    "connect succeeds, then fails, then succeeds" flapping in the original
    report. Fixed with two backstops: the W5500's own TCP keep-alive, so the chip
    probes an idle peer and drops the socket by its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
    [netcfg.cpp]
2026-08-04 brain: add a hardware watchdog to loop()
    Defence in depth. The blocking-call bugs that used to freeze loop() are fixed
    at source, but the outputs are live during bench runs and an instrument that
    stops servicing its front panel must not stay that way until someone notices
    and power-cycles it.
    Armed at the end of setup() so the bounded-but-slow bring-up (DHCP, the OLED
    reset delays, the EEPROM reads) is never counted against it, and fed at the
    end of every loop(). 4 s is far above any legitimate pass - the slowest are a
    DHCP renewal at ~1 s worst case and an EEPROM.commit() flash erase at tens of
    ms - so only a genuine wedge reaches it. A reset drops both outputs, which is
    the safe direction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
    [main.cpp]
2026-08-04 brain: always terminate an over-long SCPI response line
    Pre-existing and unrelated to the network hang; found by the malformed-input
    phase of the new stress harness.
    A ';'-chained response longer than SCPI_RESP_MAX (480 B) went out with no
    trailing LF at all, because respRaw() drops whatever it cannot fit and the
    terminator was appended through it. On a line-oriented transport the client
    then waited forever for a line that never ended - a 24-deep "*IDN?" chain
    hung the session every time.
    scpi_process_line() now writes the terminator directly. The response is still
    truncated when it does not fit, but it is always a complete line.
    Note a line longer than NET_LINE_MAX (256 B) is still answe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
2026-08-04 eval: add a SCPI network stress and liveness harness
    net_stress.py drives the brain's SCPI interface through eleven workload
    phases, each aimed at one suspected firmware path: steady soak, max-rate
    queries, connect/close churn, mid-response RST, abandoned sessions, a shut
    receive window, pool oversubscription, slowloris dribbling, malformed and
    over-long lines, a MEASure flood, and all of them at once.
    The useful part is the background monitor. It samples the LAN session, the
    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
2026-08-04 docs: record the SCPI network hang root cause and fix
    Updates the handover from "root cause not yet established" to the finished
    investigation: the socketSend() zero-window spin, the reproduction and the
    two pieces of evidence that settle it (uptime continuous across the outage,
    recovery triggered by the client rather than the instrument), the independent
    session-pool starvation bug, and a table of every change made with the
    stress-sweep results that verify them.
2026-08-04 eval: add DMM accuracy harness, measured results, and README section
    Adds Calc/evaluation/psu_accuracy.py: ramps one channel over its full range
    against a Siglent SDM3065X on raw SCPI/TCP (no VISA runtime needed) and reports
    setpoint- and readback-error as absolute, relative and linearity plots. Covers
    both voltage and current, has a live 2-point calibration mode (--calibrate
    --verify), an offline simulator, and re-plotting from a stored CSV.
    Both channels measured before and after calibration; raw CSVs, text reports and
    light/dark plots are under Calc/evaluation/results/. Summarised in the new
    README section "Measured accuracy":
    - Voltage is at its hardware floor. The setpoint error is 12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
    [ramp_ch1_20260803_233131_baseline.csv, ramp_ch1_20260803_235907_postcal.csv, ramp_ch2_20260803_233903_baseline.csv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]
2026-08-04 docs: hand over the VMEAS/IMEAS calibration bug
    Calibrating the measure paths has no measurable effect while the set paths
    demonstrably work (CH1 ISET gain +0.176 % -> -0.023 %). Writes up the evidence,
    the code path, and what has already been ruled out, so the investigation does
    not start from scratch.
    Key points captured:
    - The decisive observation is that after calibrating CH2 IMEAS at 0.2 A and
    1.8 A, the readback error at the 0.2 A cal point is unchanged (+0.39 ->
    +0.42 mA, ~4 LSB from zero). A 2-point fit must pass through its own points.
    - "commit ... stored" and CAL:VALid? = 1 are NOT evidence anything was stored.
    channel_cal_point()/channel_cal_commit() are fire-and-forget l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
2026-08-04 fix(channel): settle the calibration capture average before it is sampled
    A measure-path cal point records x from s_vadc_avg[], an EWMA of the raw ADC
    volts. Its residual after a step is (1-alpha)^n, so alpha sets the settling
    time and not just the noise floor -- and a cal point is always taken just
    after stepping the channel to it, so whatever lag is left gets fitted
    straight into the stored line.
    At alpha = 1/16 the average was still ~2 % from the new operating point
    several seconds later. Measured on CH2 at the harness's old 3 s settle: the
    x recorded at 0.2 A came out 20 mV high and the one at 1.8 A 22 mV low, each
    pulled back toward the other point, storing a 2.2 % IMEAS gain error. Th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
    [measure.cpp]
2026-08-04 eval: verify the cal residual, exclude unreachable endpoints, two-panel plots
    psu_accuracy.py reported a calibration as "stored" whenever the SCPI error
    queue was empty, which says nothing: CAL:POINt/CAL:COMMit are fire-and-forget
    and CAL:DATA? returns NaN. After committing, it now re-drives each cal point
    and prints the readback residual, warning above 5 ADC LSB. A 2-point fit must
    pass through its own two points, so that residual is the one check the
    missing observability cannot hide -- it reads +0.035/+0.155 mA on fixed
    firmware against -16.69/+17.94 mA for the same calibration before the fix.
    --cal-settle default 3 s -> 12 s. The old default is what stored a 2.2 %
    IMEAS gain error while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
    [ramp_ch1_20260803_233131_baseline.csv, ramp_ch1_20260803_235907_postcal.csv, ramp_ch2_20260803_233903_baseline.csv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]
2026-08-04 docs: record the re-measured current accuracy, retire the handover notes
    Both channels' IMEAS re-calibrated after the capture-average fix. The readback
    paths improved by an order of magnitude -- CH1 0.78 -> 0.12 mA rms, CH2 2.00
    -> 0.16 mA, gain errors +0.135 %/+0.176 % -> +0.013 %/+0.019 %. The -1.4 mA
    CH1 offset previously attributed to a shunt-vs-DMM difference was an artefact
    of the bad fit and re-fitted away.
    Voltage was re-measured and deliberately not re-calibrated: both paths sit at
    the DAC/ADC quantum with gain errors inside 0.003 %, and a day-apart repeat
    agreed to ~0.1 mV, so there is nothing for a 2-point fit to correct.
    Removes both handover notes. Their conclusions now live w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
    [net_stress.py, netcfg.cpp]
